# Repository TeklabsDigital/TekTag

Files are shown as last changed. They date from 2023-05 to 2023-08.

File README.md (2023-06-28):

# **TekTag Bio™ - The Open Source Biosensor**

Introducing the latest open-source project from Teklabs Digital™, a sophisticated state-of-the-art IoT biosensor for patient monitoring, telehealth, pressure are management in hospitals, cardiac monitoring, fall detection and dementia geofencing. This community project, released under an open source license, showcases our commitment to pushing the boundaries of digital design innovation.

**TekTag Bio™** is a cutting-edge biosensor for telehealth, patient monitoring, fall detection, dementia geofencing, and cardiograms. This repository houses all the necessary files and resources to understand, modify, and contribute to this innovative project.

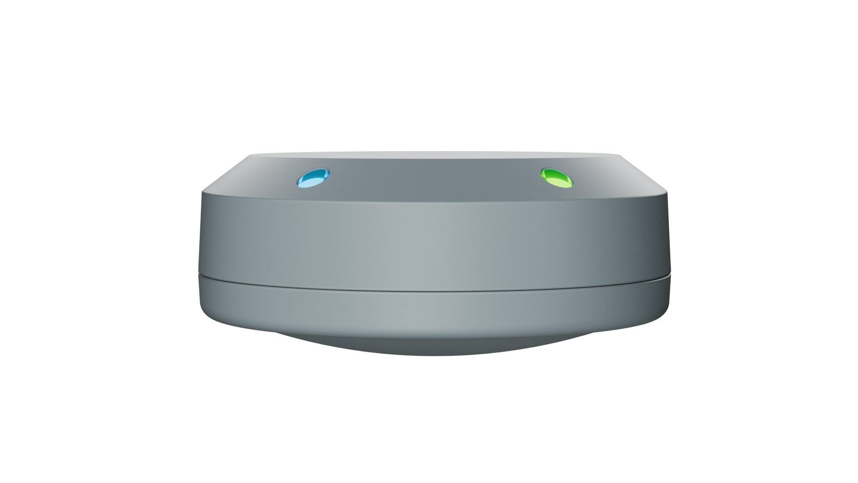
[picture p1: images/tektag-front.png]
TekTag Front


## **Table of Contents**

- [Features](#features)
- [Biosensor Applications](#biosensor-applications)
- [General Applications](#general-applications)
- [BLE Support and Mesh Technology](#ble-support-and-mesh-technology)
  - [Benefits of BLE Mesh Technology](#benefits-of-ble-mesh-technology)
- [Hardware/Electronics](#hardwareelectronics)
- [Repository Structure](#repository-structure)
- [Images](#images)
- [PCB Size and Assembly](#pcb-size-and-assembly)
- [Why is this project Open Source?](#why-is-this-project-open-source)
- [Supporting This Project](#supporting-this-project)
- [Licenses](#licenses)
- [Contact Us](#contact-us)

## [**Features**](#features)
- Small size - 28mm diameter (1.1 inches)
- All 3D manufacturing files included
- All PCB designs included
- All schematics included
- Audio feedback
- BLE 5.4 - Mesh Networking & All protocols supported by the STM32WB
- Compact integrated design
- Haptic feedback
- Qi charging
- STM32WB ARM MCU
- Touch pad for finger tap and gestures
- Ultra low power
- Visual feedback through two RGB LEDs

## [Biosensor Applications](#biosensor-applications)

Our biosensor provides a plethora of features designed to enhance the quality of life for individuals and improve the capabilities of healthcare providers. It includes:

- Telehealth capabilities
- Patient monitoring
- Pressure area management - bed turn and movement detection
- Cardiac monitoring via Ballistocardiology (BCG)
- Patient Fall detection
- Dementia geo-fence alerting
- Respiratory monitoring
- Sleep pattern monitoring

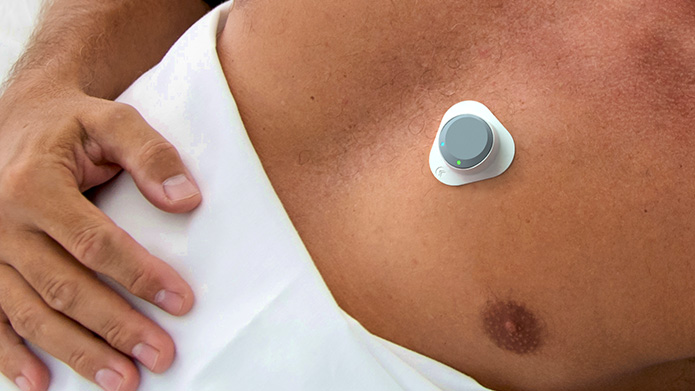
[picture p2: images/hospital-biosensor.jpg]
Hospital Biosensor


## [General Applications](#general-applications)

The small size, wireless Bluetooth, hermetically sealed enclosure, and Qi charging features of the sensor make it versatile enough to be used in a wide variety of applications, such as:

- Sports Performance Analysis
- Physical Therapy
- Elderly Care
- Virtual Reality (VR)/ Augmented Reality (AR) Systems
- Gaming
- Industrial Monitoring
- Sleep Studies
- Dance Choreography
- Wildlife Studies
- Security Systems

## [BLE Support and Mesh Technology](#ble-support-and-mesh-technology)

One of the key features of the TekTag Bio™ is its compatibility with the STM32WB ecosystem, which offers support for a variety of Bluetooth Low Energy (BLE) protocols. BLE is a power-efficient version of classic Bluetooth and is designed for short-range communication between devices. 

A particularly exciting protocol within this ecosystem is BLE Mesh technology. BLE Mesh allows for many-to-many communication, creating a network of interconnected devices that can communicate with each other. This is an essential feature when deploying large numbers of TekTag Bio™ devices in a hospital setting.

### [Benefits of BLE Mesh Technology](#benefits-of-ble-mesh-technology)

There are several key benefits of using BLE Mesh technology in a TekTag Bio™ deployment:

1. **Scalability**: BLE Mesh networks can theoretically support up to 32,767 devices, making them highly scalable. This is ideal for large-scale deployments in hospitals, where you might need to monitor many patients simultaneously.
2. **Reliability**: In a mesh network, data can take multiple paths to reach its destination, which increases the network's overall reliability. If one device fails or is disconnected, the network can automatically reconfigure itself to ensure data still reaches its destination.
3. **Range**: While individual BLE devices have a limited range, a mesh network can extend that range significantly. Each device in the network can act as a relay, passing messages from one device to another. This allows data to travel large distances across the network, making it possible to cover an entire hospital.
4. **Power Efficiency**: Despite their capabilities, BLE Mesh networks are highly power efficient. This is crucial for TekTag Bio™ devices, which need to operate for extended periods without recharging.

## [Hardware/Electronics](#hardwareelectronics)

Our biosensor utilizes a range of high-performance components to achieve its functionality:

- **STM32WB55VG:** This is a BLE 5.3 dual-core, multi-protocol 2.4 GHz radio and ultra-low-power MCU system on chip. Supporting mesh networking, the STM32WB is the brain of our sensor and responsible for signal processing and wireless communication.

- **MLPF-WB55-01E3:** This is an integrated filter module for STM32WB55, by ST. It increases board space through reduced PCB component count.

- **BQ51052BYFP:** This is a high-efficiency, Qi-compliant wireless power receiver. It enables our sensor to be charged wirelessly.

- **TLV75533PDRV:** This is a low-dropout (LDO) regulator with high power-supply rejection ratio (PSRR). It helps to provide stable power supply for our sensor.

- **KTD2052:** This is an LED driver used for status indication in our sensor.

- **LSM6DSV16XTR:** This is a system-in-package featuring a 3D digital accelerometer and a 3D digital gyroscope. It enables our sensor to detect and log movements.

## [Repository Structure](#repository-structure)

This repository is organized into several key sections:

- **Electronics:** Schematics, PCB updates and files related to the electronic components of the TekTag Bio™ biosensor.
- **Firmware/stm32:** The initial commit of the firmware for the STM32 microcontroller used in the device.
- **Mechanical:** Files related to the mechanical aspects of the biosensor, including design and assembly instructions.

## [Images](#images)

Below are some images related to the project:

### PCB Front - 6 Layers
Having a six-layer PCB with tented vias under a BGA (Ball Grid Array) is important for our product's compact size, signal integrity, thermal management, and reliability. The extra layers allow for denser routing, reducing PCB size. Tented vias prevent solder draw into vias, preventing assembly problems under tight constraints.

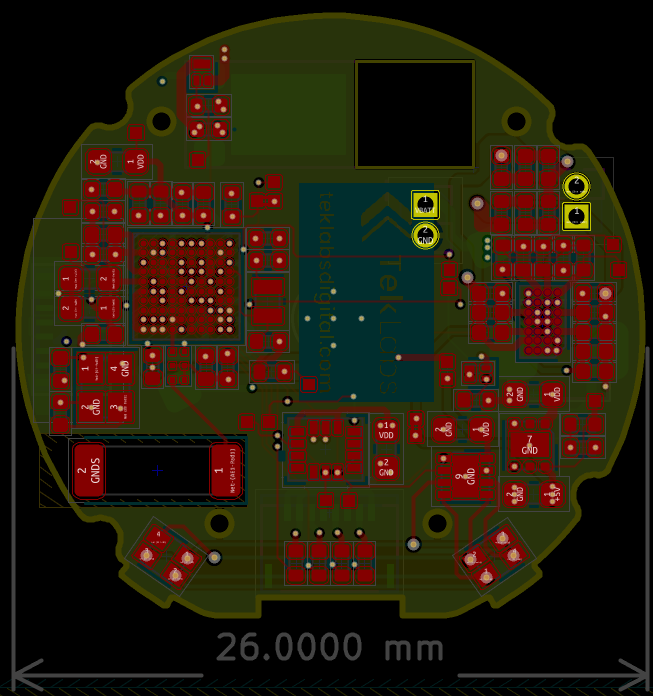
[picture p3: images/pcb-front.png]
TekTag Bio™ PCB Front


### PCB Front 3D

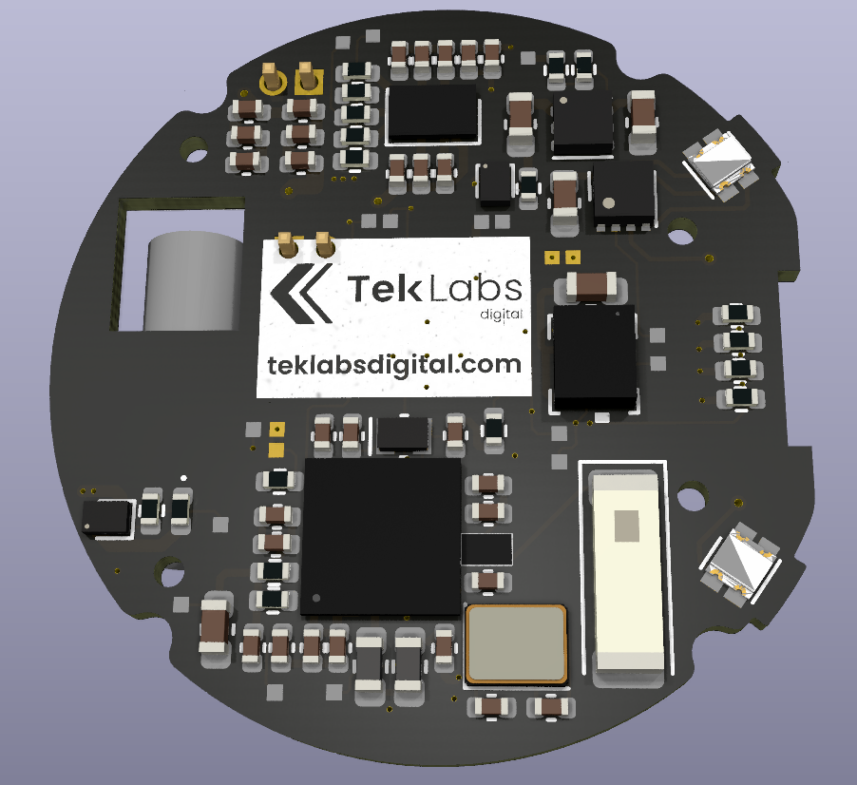
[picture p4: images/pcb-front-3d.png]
TekTag Bio™ PCB Front 3D


### PCB Back 3D

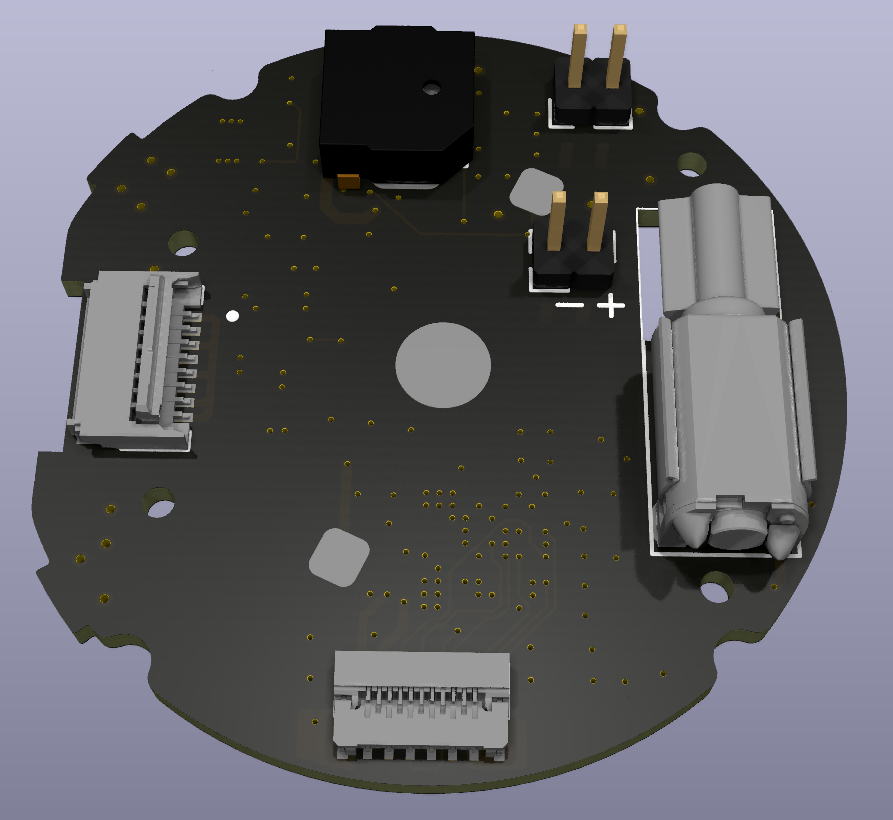
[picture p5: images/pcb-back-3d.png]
TekTag Bio™ PCB Back 3D


### TekTag Bio™ Sensor with Silicon Holder

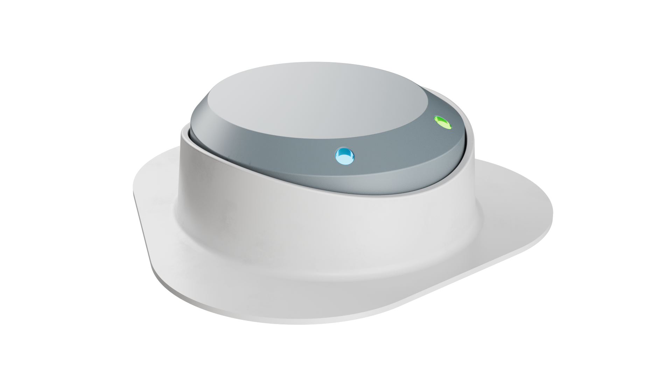
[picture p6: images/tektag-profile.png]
TekTag Bio™ Profile


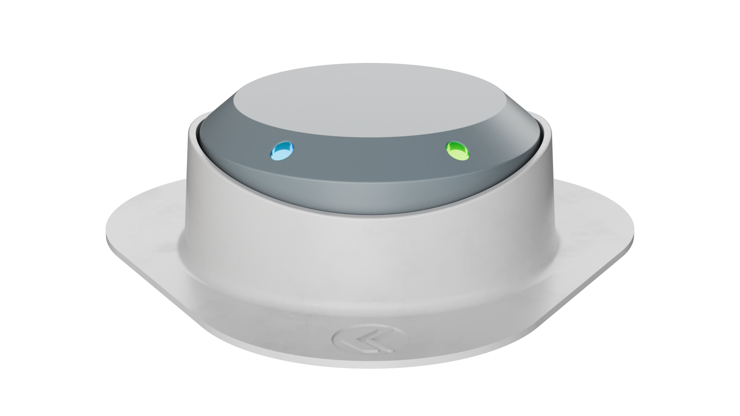
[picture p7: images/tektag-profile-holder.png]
TekTag Bio™ Profile Holder


### TekTag Bio™ Sensor Without Silicone Holder

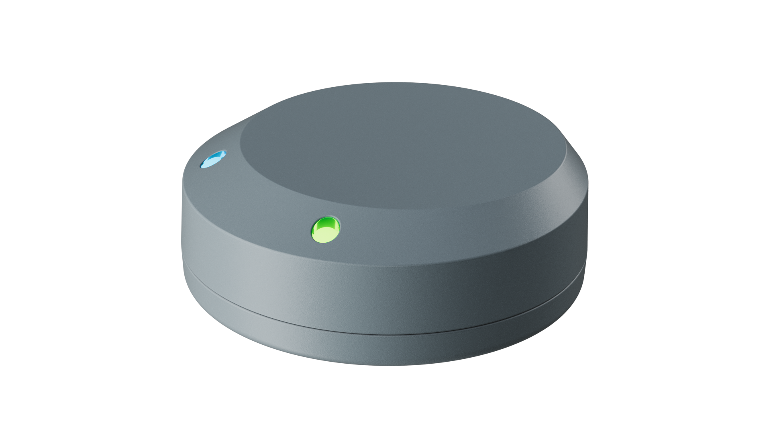
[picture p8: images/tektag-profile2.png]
TekTag Bio™ Profile 2


## [PCB Size and Assembly](#pcb-size-and-assembly)

The TekTag Bio™ is designed with a compact and highly-integrated PCB (Printed Circuit Board). Given its small size, specialized tools and expertise are required for the assembly process. This could pose a challenge for individual builders, especially those without access to such resources.

Understanding this, if there is enough interest from the community, we are prepared to step in and help. We plan to manufacture and assemble the boards for everyone at minimal cost. This not only ensures the quality and consistency of the boards but also makes the TekTag Bio™ more accessible to everyone interested in using or contributing to it.

## [Why is this project Open Source?](#why-is-this-project-open-source)

TekTag Bio™ is a project rooted in the belief that quality healthcare should be accessible to everyone, regardless of where they are in the world. By open sourcing this project, we are aiming to democratize access to technology that has the potential to significantly improve patient outcomes, particularly in developing countries where resources may be limited. 

There are several reasons why we believe an open source approach is best for this project:

1. **Community Collaboration**: Open source projects foster a unique sense of collaboration and community. People from all around the world can contribute to the project, each bringing their unique perspectives and skills to the table. This diversity can drive innovation and improve the product in ways that wouldn't be possible in a closed source project.

2. **Accelerated Development**: With more eyes on the project, issues can be identified and resolved more quickly. This can speed up the development process and result in a better final product.

3. **Transparency**: Open source projects are transparent. Anyone can look at the code and understand exactly how the product works. This transparency can build trust and make it easier for people to adopt the technology.

4. **Accessibility**: Perhaps the most important reason is that open source projects are accessible to everyone. Anyone, anywhere, can use and modify the product for their own needs. This is particularly important for healthcare technology, which has the potential to save lives and improve quality of life for millions of people.

5. **Non-profit Motivation**: As a non-profit initiative, our primary goal is to support health outcomes worldwide. Our focus is on creating a product that can have a real impact on the world, not on generating profit.

6. **Education**: Open sourcing this project also provides a valuable learning resource for students and professionals interested in biosensor technology. They can learn from and build upon the work that's already been done, accelerating their own learning and development.

By open sourcing TekTag Bio™, we hope to create a product that's not only effective, but also widely accessible and continually improving. This is our contribution to supporting healthcare in both developing countries and in first world hospitals where critical care is needed. We invite you to join us in this endeavor, whether it's by using TekTag Bio™, contributing to its development, or simply learning from the project.

## [Supporting This Project](#supporting-this-project)

TekTag Bio™ is a community-driven project, and we welcome contributions from everyone, regardless of their background or experience level. There are several ways you can support this project:

1. **Contributing Code**: If you have experience in UX/UI for the web application, Node.js for backend development, Express.js for the frontend, or STM32WB firmware engineering, your skills are particularly valuable. You can contribute directly to the codebase, helping us improve and expand the functionality of TekTag Bio™.

2. **Testing and Reporting Issues**: Even if you're not a developer, you can still contribute by testing the TekTag Bio™ and reporting any issues or bugs you find. This helps us ensure that the TekTag Bio™ is as reliable and effective as possible.

3. **Spreading the Word**: Help us grow the TekTag Bio™ community by sharing the project with others. The more people who know about TekTag Bio™, the more we can achieve.

4. **Donations**: As a not-for-profit project, we rely on donations to fund our work. If you're able to, consider making a donation to support the development of TekTag Bio™.

5. **Partnerships**: We are open to partnerships with organizations that align with our mission of improving healthcare outcomes worldwide. If you represent such an organization, please get in touch.

## [Licenses](#licenses)
Project source code, hardware designs and 3d enclosure designs are open source and licensed under the terms of the attached license, with attribution to TekLabs Digital Pty Ltd, Australia

## [Contact Us](#contact-us)
If you're interested in contributing to the TekTag Bio™ project, please contact us through our website at [https://teklabsdigital.com/contact/](https://teklabsdigital.com/contact/). We look forward to working with you to make TekTag Bio™ the best it can be!

Remember, every contribution, no matter how small, helps us move closer to our goal of improving healthcare outcomes around the world. Thank you for your support!

About TekLabs Digital Pty Ltd, Australia - Creating exceptional IoT products and advanced technologies to improve our quality of life 🌟IoT product research, innovation and design✨Let's get started!
web www.teklabsdigital.com
linkedin https://www.linkedin.com/in/trevorattemadigital/
Contact us about your design today.

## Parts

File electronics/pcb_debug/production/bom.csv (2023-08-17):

Designator | Footprint | Quantity | Value | LCSC Part #
J1 | Molex 5035661102 | 1 | SWD Trace
J2 | PinHeader_2x10_P1.27mm_Vertical | 1 | SWD Trace J Trace
J3 | PinHeader_2x05_P1.27mm_Vertical | 1 | SWD Debug
J4 | PinHeader_1x01_P2.54mm_Vertical | 1 | 5V
J5 | PinHeader_1x01_P2.54mm_Vertical | 1 | GND
JP1 | PinHeader_1x02_P2.54mm_Vertical | 1 | 5V Trace

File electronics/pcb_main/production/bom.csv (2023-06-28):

Designator | Footprint | Quantity | Value | LCSC Part #
AE1 | Johanson_2450AT43B100E | 1 | BLE Antenna
BOOT0 | MicroJump | 1 | Bridge
BT1 | CP1254 Battery | 1 | Battery_Cell
BZ1 | Transducer TE044003-4 | 1 | Buzzer
C1, C2 | 0402 | 2 | 18pF
C10, C11, C12, C13, C14, C15, C7, C8, C9 | 0402 | 9 | 100nF
C16, C17, C18 | 0402 | 3 | C1
C19, C20, C21 | 0402 | 3 | C2
C22, C27 | 0402 | 2 | 0.47uF
C23, C26 | 0402 | 2 | 22nF
C24, C25 | 0402 | 2 | 10nF
C28, C29 | 0402 | 2 | 10uF
C3, C4 | 0402 | 2 | 12pF
C30, C31, C32, C33 | 0603 | 4 | 10uF
C34 | 0402 | 1 | 1uF
C35 | 0402 | 1 | 47nF
C6 | 0603 | 1 | 4.7uF
D1 | LED_LiteOn_LTST-C19HE1WT | 1 | LEDA
D2 | LED_LiteOn_LTST-C19HE1WT | 1 | LEDB
D3 | 0402 | 1 | 1N4148
J1 | Molex 5035661102 | 1 | SWD Trace
J2 | MOLEX_5034800800 | 1 | Touch FFC
J3 | PinHeader_1x02_P1.27mm_Vertical | 1 | ExtBatt
JP1 | MicroJump-Open | 1 | 5V Trace
JP2 | MicroJump | 1 | Batt Source
L1 | 0603 | 1 | 10uH
L2 | 0603 | 1 | 10nH
L3 | PinHeader_1x02_P1.27mm_Vertical | 1 | RX Coil
M1 | SMT Motor VZ43FM1B8230001L | 1 | Motor_DC
Q1, Q2 | SOT-883 | 2 | 2N7002
R1, R12, R13, R14, R15, R2 | 0402 | 6 | 1K
R10, R11 | 0402 | 2 | 1M
R16 | 0402 | 1 | 1.5M
R3, R8 | 0402 | 2 | 47K
R4 | 0402 | 1 | 2K4
R5 | 0402 | 1 | 100K
R6 | 0402 | 1 | 820R
R7 | 0402 | 1 | 220R
R9 | 0402 | 1 | 3.3M
TH1 | 0402 | 1 | 10k???
U1 | STM32WB55VGY6TR | 1 | STM32WB55VGY6TR - Seq
U3 | MLPF-WB55-01E3 | 1 | MLPF-WB55-01E3
U4 | Texas_DSBGA-28_1.9x3.0mm_Layout4x7_P0.4mm | 1 | BQ51052BYFP
U5 | WSON-6-1EP_2x2mm_P0.65mm_EP1x1.6mm | 1 | TLV75533PDRV
U6 | DFN-8-1EP_2x2mm_P0.5mm_EP1.05x1.75mm | 1 | KTD2052
U7 | LSM6DSV16XTR | 1 | LSM6DSV16XTR
Y1 | Crystal_SMD_EuroQuartz_X22-4Pin_2.5x2.0mm | 1 | 32MHz
Y2 | Crystal_SMD_MicroCrystal_CM9V-T1A-2Pin_1.6x1.0mm | 1 | 32768kHz

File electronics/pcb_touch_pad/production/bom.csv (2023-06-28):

Designator | Footprint | Quantity | Value | LCSC Part #
J1 | FFC_12_FLEX_PCB_END | 1 | Touch FFC
T1 | TouchSlider-3_12x12mm | 1 | TouchSlider-3x3

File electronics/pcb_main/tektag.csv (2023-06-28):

Ref | Qnty | Value | Cmp name | Footprint | Description | Vendor
AE1, | 1 | BLE Antenna | Antenna_Chip | TekLabs:Johanson_2450AT43B100E | Ceramic chip antenna with pin for PCB trace
BOOT0, | 1 | Bridge | SolderJumper_2_Bridged | TekLabs:MicroJump | Solder Jumper, 2-pole, closed/bridged
BT1, | 1 | Battery_Cell | Battery_Cell | TekLabs:CP1254 Battery | Single-cell battery
BZ1, | 1 | Buzzer | Buzzer | TekLabs:Transducer TE044003-4 | Buzzer, polarized
C1, C2, | 2 | 18pF | C_Small | Capacitor_SMD:C_0402_1005Metric | Unpolarized capacitor, small symbol
C16, C17, C18, | 3 | C1 | C_Small | Capacitor_SMD:C_0402_1005Metric | Unpolarized capacitor, small symbol
C19, C20, C21, | 3 | C2 | C_Small | Capacitor_SMD:C_0402_1005Metric | Unpolarized capacitor, small symbol
C22, C27, | 2 | 0.47uF | C_Small | Capacitor_SMD:C_0402_1005Metric | Unpolarized capacitor, small symbol
C23, C26, | 2 | 22nF | C_Small | Capacitor_SMD:C_0402_1005Metric | Unpolarized capacitor, small symbol
C24, C25, | 2 | 10nF | C_Small | Capacitor_SMD:C_0402_1005Metric | Unpolarized capacitor, small symbol
C28, C29, | 2 | 10uF | C_Small | Capacitor_SMD:C_0402_1005Metric | Unpolarized capacitor, small symbol
C3, C4, | 2 | 12pF | C_Small | Capacitor_SMD:C_0402_1005Metric | Unpolarized capacitor, small symbol
C30, C31, C32, C33, | 4 | 10uF | C_Small | Capacitor_SMD:C_0603_1608Metric | Unpolarized capacitor, small symbol
C34, | 1 | 1uF | C_Small | Capacitor_SMD:C_0402_1005Metric | Unpolarized capacitor, small symbol
C35, | 1 | 47nF | C_Small | Capacitor_SMD:C_0402_1005Metric | Unpolarized capacitor, small symbol
C6, | 1 | 4.7uF | C_Polarized_Small_US | Capacitor_SMD:C_0603_1608Metric | Polarized capacitor, small US symbol
C7, C8, C9, C10, C11, C12, C13, C14, C15, | 9 | 100nF | C_Small | Capacitor_SMD:C_0402_1005Metric | Unpolarized capacitor, small symbol
D1, | 1 | LEDA | LED_RGBA | LED_SMD:LED_LiteOn_LTST-C19HE1WT | RGB LED, red/green/blue/anode
D2, | 1 | LEDB | LED_RGBA | LED_SMD:LED_LiteOn_LTST-C19HE1WT | RGB LED, red/green/blue/anode
D3, | 1 | 1N4148 | 1N4148 | Diode_SMD:D_0402_1005Metric | 100V 0.15A standard switching diode, DO-35
J1, | 1 | SWD Trace | Conn_01x11 | TekLabs:Molex 5035661102 | Generic connector, single row, 01x11, script generated (kicad-library-utils/schlib/autogen/connector/)
J2, | 1 | Touch FFC | Conn_01x08 | TekLabs:MOLEX_5034800800 | Generic connector, single row, 01x08, script generated (kicad-library-utils/schlib/autogen/connector/)
J3, | 1 | ExtBatt | Conn_01x02 | Connector_PinHeader_1.27mm:PinHeader_1x02_P1.27mm_Vertical | Generic connector, single row, 01x02, script generated (kicad-library-utils/schlib/autogen/connector/)
JP1, | 1 | 5V Trace | SolderJumper_2_Open | TekLabs:MicroJump-Open | Solder Jumper, 2-pole, open
JP2, | 1 | Batt Source | SolderJumper_2_Bridged | TekLabs:MicroJump | Solder Jumper, 2-pole, closed/bridged
L1, | 1 | 10uH | L_Small | Inductor_SMD:L_0603_1608Metric | Inductor, small symbol
L2, | 1 | 10nH | L_Small | Inductor_SMD:L_0603_1608Metric | Inductor, small symbol
L3, | 1 | RX Coil | L_Small | Connector_PinHeader_1.27mm:PinHeader_1x02_P1.27mm_Vertical | Inductor, small symbol
M1, | 1 | Motor_DC | Motor_DC | TekLabs:SMT Motor VZ43FM1B8230001L | DC Motor
Q1, Q2, | 2 | 2N7002 | 2N7002 | Package_TO_SOT_SMD:SOT-883 | 0.115A Id, 60V Vds, N-Channel MOSFET, SOT-23
R1, R2, R12, R13, R14, R15, | 6 | 1K | R_Small_US | Resistor_SMD:R_0402_1005Metric | Resistor, small US symbol
R10, R11, | 2 | 1M | R_Small | Resistor_SMD:R_0402_1005Metric | Resistor, small symbol
R16, | 1 | 1.5M | R_Small_US | Resistor_SMD:R_0402_1005Metric | Resistor, small US symbol
R3, R8, | 2 | 47K | R_Small_US | Resistor_SMD:R_0402_1005Metric | Resistor, small US symbol
R4, | 1 | 2K4 | R_Small_US | Resistor_SMD:R_0402_1005Metric | Resistor, small US symbol
R5, | 1 | 100K | R_Small_US | Resistor_SMD:R_0402_1005Metric | Resistor, small US symbol
R6, | 1 | 820R | R_Small_US | Resistor_SMD:R_0402_1005Metric | Resistor, small US symbol
R7, | 1 | 220R | R_Small_US | Resistor_SMD:R_0402_1005Metric | Resistor, small US symbol
R9, | 1 | 3.3M | R_Small_US | Resistor_SMD:R_0402_1005Metric | Resistor, small US symbol
TH1, | 1 | 10k??? | Thermistor_NTC_US | Resistor_SMD:R_0402_1005Metric | Temperature dependent resistor, negative temperature coefficient, US symbol
U1, | 1 | STM32WB55VGY6TR - Seq | STM32WB55VGY6TR - Seq | TekLabs:STM32WB55VGY6TR
U3, | 1 | MLPF-WB55-01E3 | MLPF-WB55-01E3 | TekLabs:MLPF-WB55-01E3 | 2.4 GHz Matched filter companion chip for STM32WB55Cx and STM32WB55Rx
U4, | 1 | BQ51052BYFP | BQ51052BYFP | Package_BGA:Texas_DSBGA-28_1.9x3.0mm_Layout4x7_P0.4mm | Qi v1.2, Wireless Power Receiver and Battery Charger, Vout 4.40V, DSBGA-28
U5, | 1 | TLV75533PDRV | TLV75533PDRV | Package_SON:WSON-6-1EP_2x2mm_P0.65mm_EP1x1.6mm | 500mA Low Dropout Voltage Regulator, Fixed Output 3.3V, WSON6
U6, | 1 | KTD2052 | KTD2052 | Package_DFN_QFN:DFN-8-1EP_2x2mm_P0.5mm_EP1.05x1.75mm | 12 Channel RGB LED Drivers with I2C control
U7, | 1 | LSM6DSV16XTR | LSM6DSV16XTR | TekLabs:LSM6DSV16XTR
Y1, | 1 | 32MHz | Crystal_GND24_Small | Crystal:Crystal_SMD_EuroQuartz_X22-4Pin_2.5x2.0mm | Four pin crystal, GND on pins 2 and 4, small symbol
Y2, | 1 | 32768kHz | Crystal_Small_1 | Crystal:Crystal_SMD_MicroCrystal_CM9V-T1A-2Pin_1.6x1.0mm | 32.768 kHz Â±100ppm Crystal 7pF 90 kOhms 2-SMD, No Lead

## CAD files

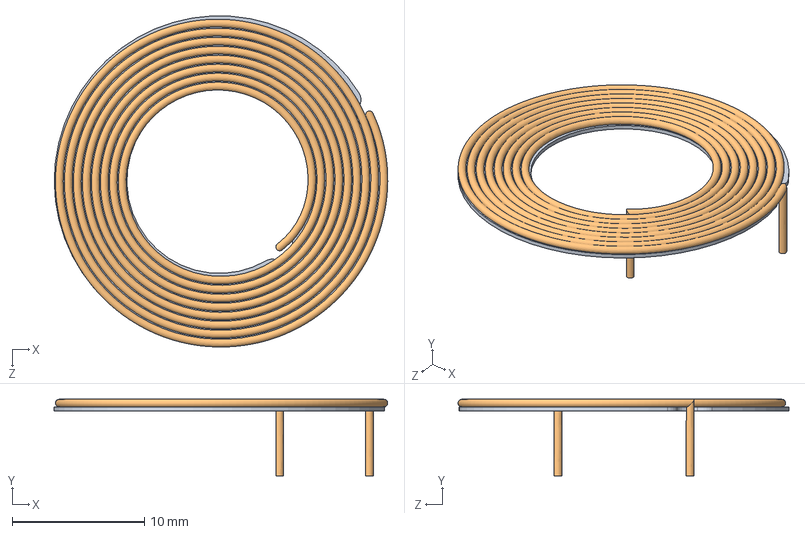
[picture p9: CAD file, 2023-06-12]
mechanical/SOLIDWORKS ORIGINAL FILE/ASSEMBLY WIRELESS CHARGING.SLDASM
25.3 x 5.79 x 25.1 mm
FERRITE
WIRELESS CHARGING COIL

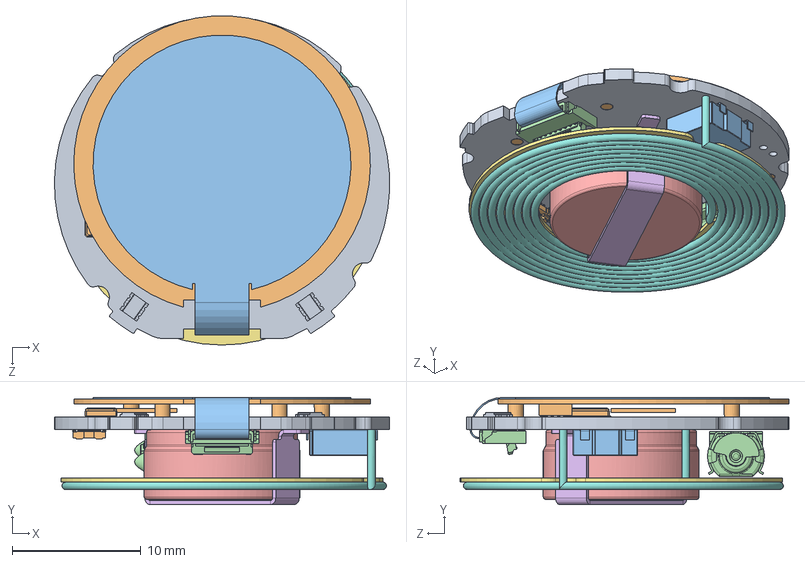
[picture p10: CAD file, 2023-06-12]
mechanical/SOLIDWORKS ORIGINAL FILE/ASSEMBLY PCB.SLDASM
26.0 x 8.30 x 25.5 mm
PCB
ELECTRONIC PART
BUZZER
VZ43FM1B8230001L
BATTERY CP1254 A3
BATTERY BRACKET
FERRITE
WIRELESS CHARGING COIL
LED LTST-C19HE1WT x 2
INNER FRAME REV
FLEXIBLE PCB
CONNECTOR

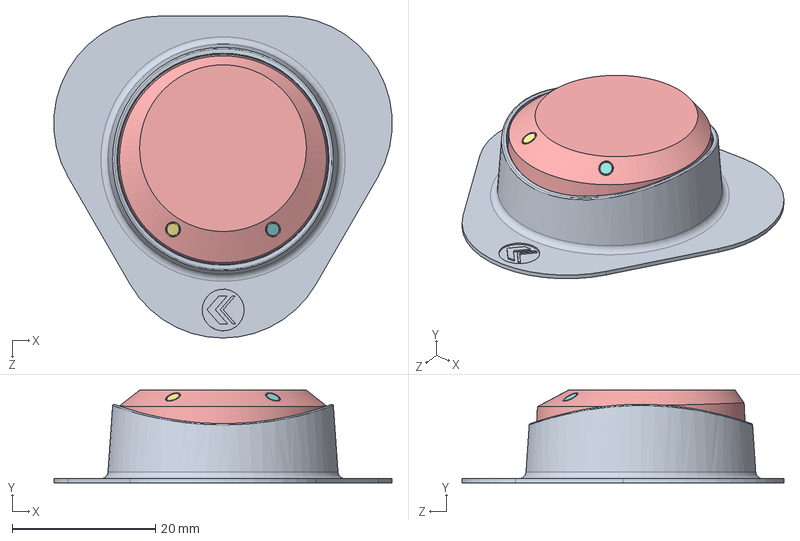
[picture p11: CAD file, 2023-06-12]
mechanical/SOLIDWORKS ORIGINAL FILE/ASSEMBLY FULL.SLDASM
47.2 x 13.0 x 45.0 mm
PCB
ELECTRONIC PART
BUZZER
VZ43FM1B8230001L
BATTERY CP1254 A3
BATTERY BRACKET
FERRITE
WIRELESS CHARGING COIL
LED LTST-C19HE1WT
INNER FRAME REV
FLEXIBLE PCB
CONNECTOR
TOP COVER
BUTTOM COVER
LED LIGHT PIPE
Mirror LED LIGHT PIPE
HOLDER

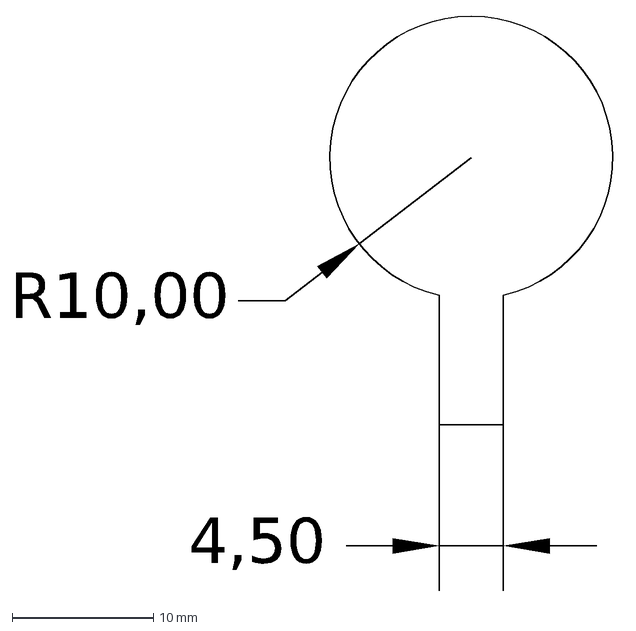
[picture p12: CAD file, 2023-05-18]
electronics/pcb_touch_pad/FLEXIBLE PCB.dxf
R10,00
4,50

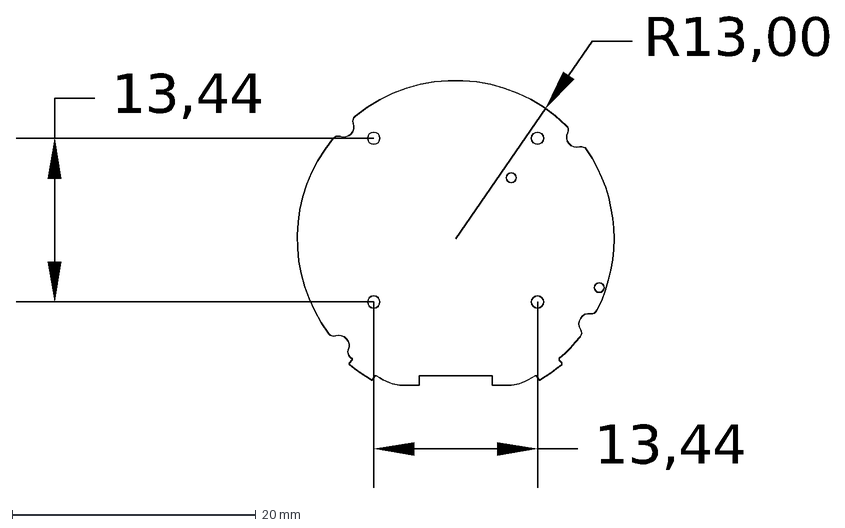
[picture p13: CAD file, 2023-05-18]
electronics/pcboutline/PCB.dxf
R13,00
13,44

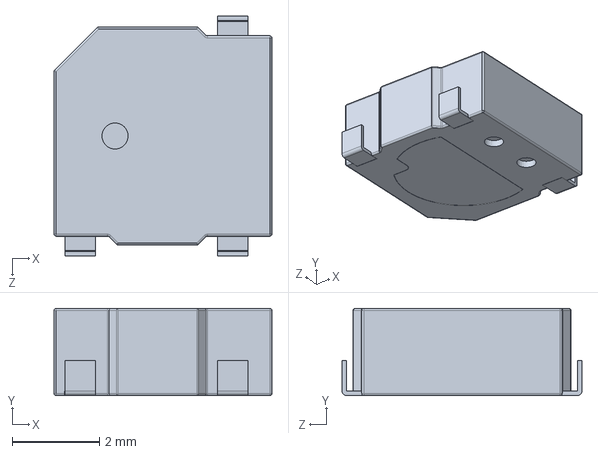
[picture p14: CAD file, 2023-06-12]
mechanical/SOLIDWORKS ORIGINAL FILE/BUZZER V1.SLDPRT
5.00 x 2.00 x 5.50 mm

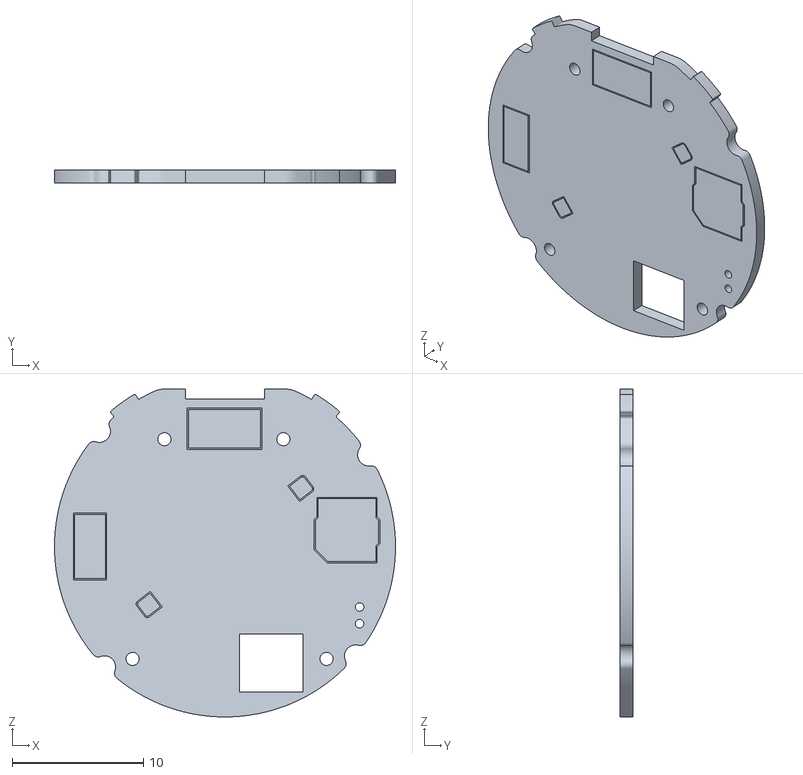
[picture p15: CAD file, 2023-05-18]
mechanical/STL FILE/PCB.STL
26.0 x 1.00 x 25.0

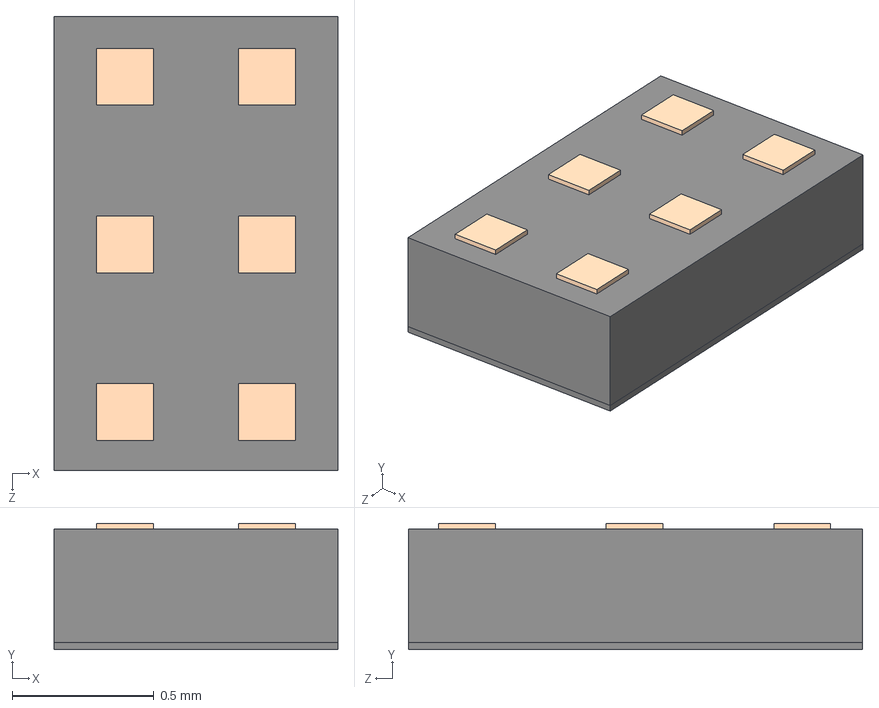
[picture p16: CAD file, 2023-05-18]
electronics/pcb_main/3dfiles/MLPF-WB55-01E3.stp
1.00 x 0.445 x 1.60 mm

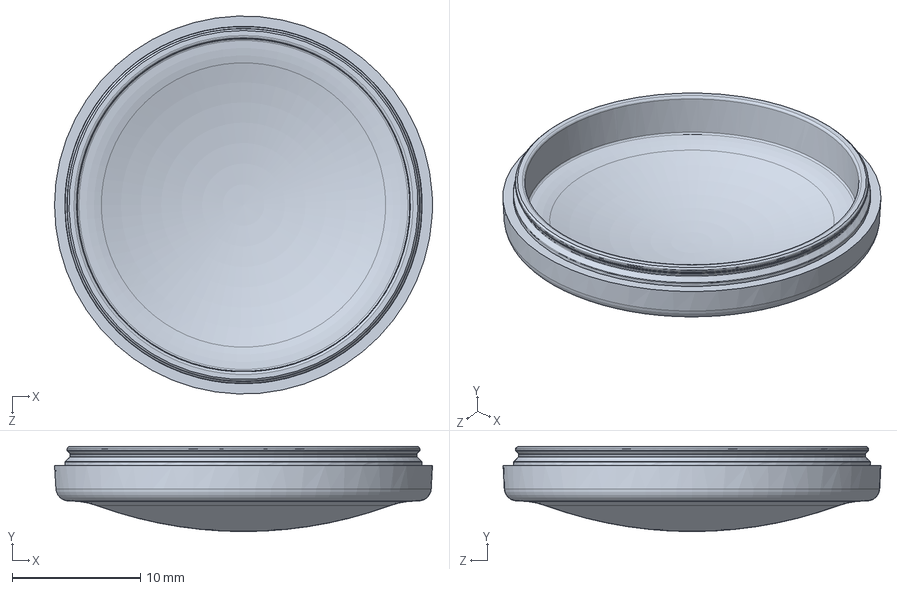
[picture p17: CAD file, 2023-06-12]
mechanical/SOLIDWORKS ORIGINAL FILE/BUTTOM COVER.SLDPRT
29.4 x 6.63 x 29.4 mm

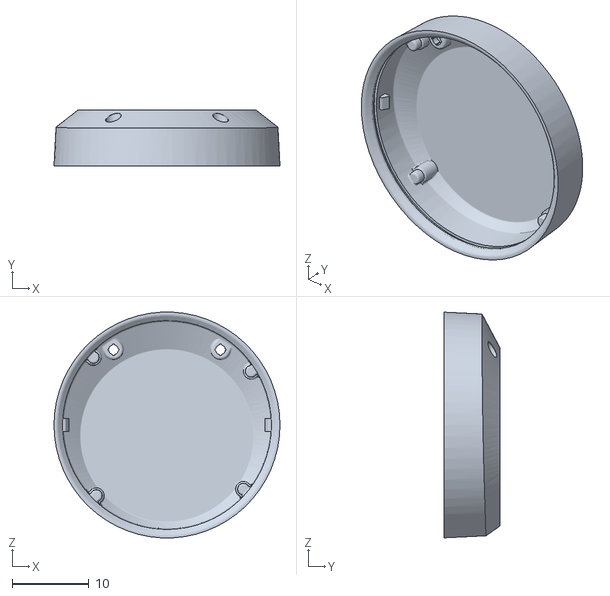
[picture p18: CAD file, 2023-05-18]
mechanical/STL FILE/TOP COVER.STL
29.4 x 7.24 x 29.4

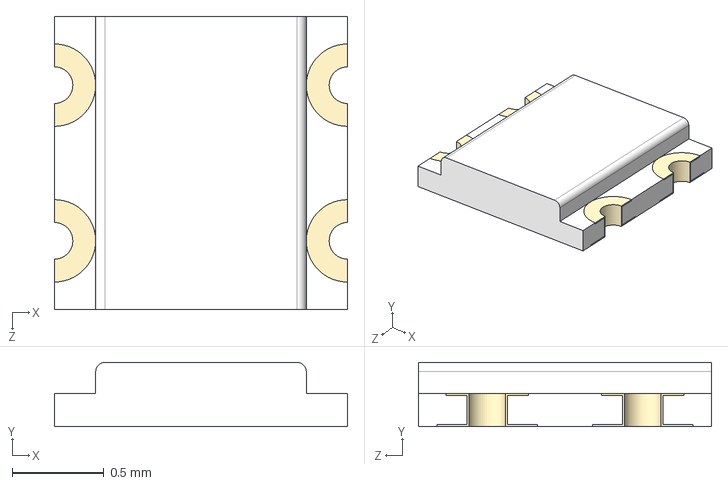
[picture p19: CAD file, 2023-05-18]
electronics/pcb_main/3dfiles/LTST-C19HE1WT.step
1.60 x 0.35 x 1.60 mm

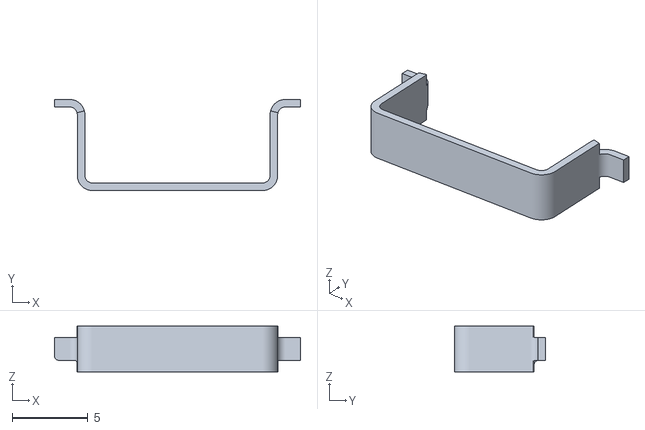
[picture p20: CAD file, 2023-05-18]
mechanical/STL FILE/BATTERY BRACKET.STL
16.2 x 6.00 x 3.00

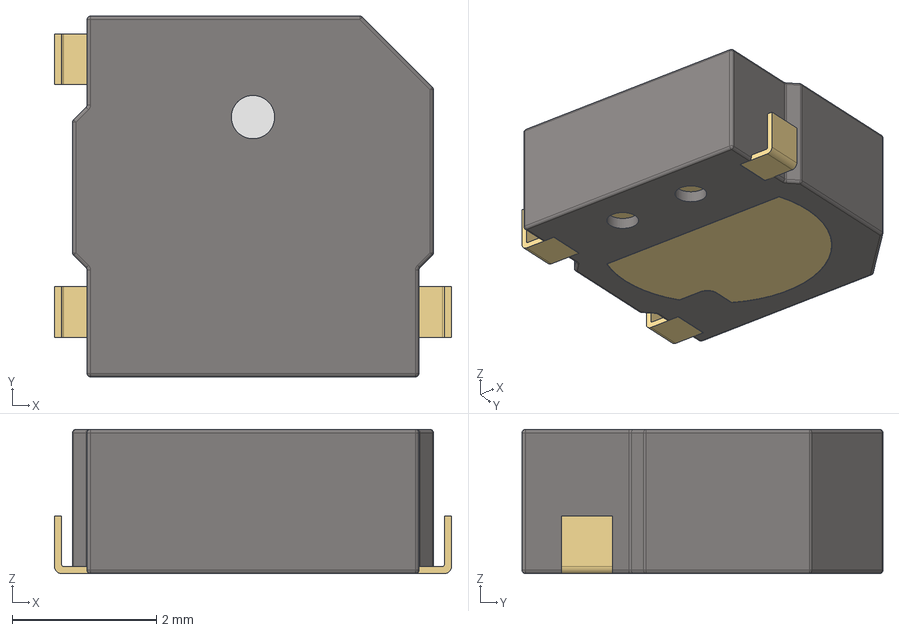
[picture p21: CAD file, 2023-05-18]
electronics/pcb_main/3dfiles/SMT-0540-T-7-R--3DModel-STEP-1.STEP
5.50 x 5.00 x 2.00 mm

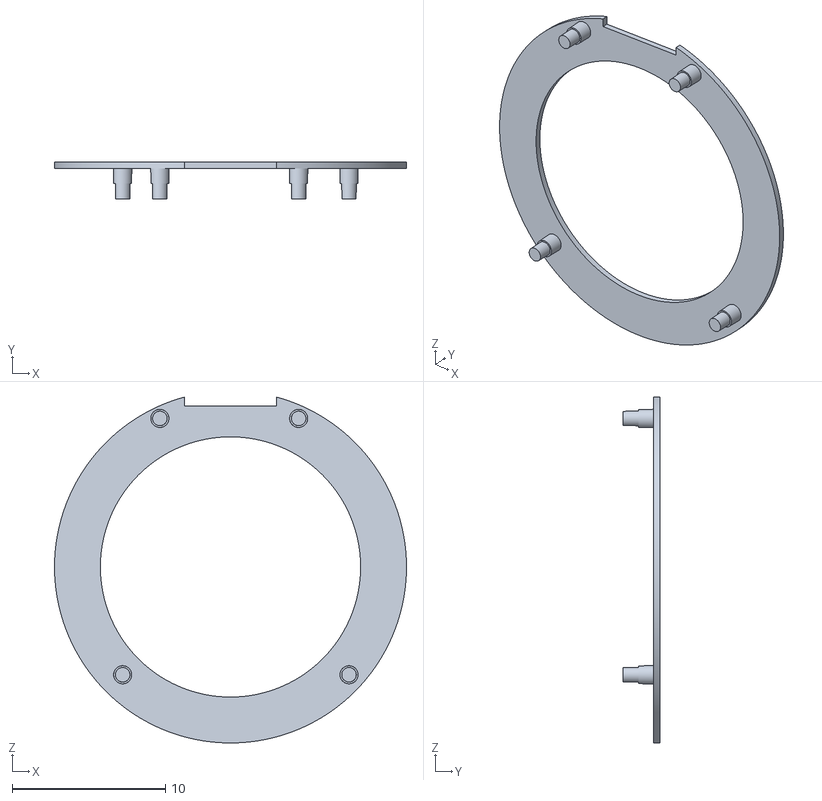
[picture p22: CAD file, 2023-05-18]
mechanical/STL FILE/INNER FRAME REV.STL
23.0 x 2.40 x 22.6

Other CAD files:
mechanical/SOLIDWORKS ORIGINAL FILE/BUZZER.SLDPRT
mechanical/SOLIDWORKS ORIGINAL FILE/LED LIGHT PIPE.SLDPRT
mechanical/STL FILE/FLEXIBLE PCB.STL
mechanical/SOLIDWORKS ORIGINAL FILE/CONNECTOR.SLDPRT
electronics/pcb_main/3dfiles/5034800800.step
electronics/pcb_main/3dfiles/5035481220.step
electronics/pcb_main/3dfiles/503566-1102.stp
electronics/pcb_main/3dfiles/BQ51052BYFPT.STEP
electronics/pcb_main/3dfiles/DFN_NP3-T1GE4_VIS.step
electronics/pcb_main/3dfiles/LGA14L_LSM6_STM.step
electronics/pcb_main/3dfiles/UFBGA129_STM32WB55VGQ6_STM.step
mechanical/DWG/FLEXIBLE PCB.DWG
mechanical/DWG/PCB.DWG
mechanical/SOLIDWORKS ORIGINAL FILE/3D/ASSEMBLY FULL.SLDASM
mechanical/SOLIDWORKS ORIGINAL FILE/3D/ASSEMBLY PCB.SLDASM
mechanical/SOLIDWORKS ORIGINAL FILE/3D/ASSEMBLY WIRELESS CHARGING.SLDASM
mechanical/SOLIDWORKS ORIGINAL FILE/3D/BATTERY BRACKET.SLDPRT
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

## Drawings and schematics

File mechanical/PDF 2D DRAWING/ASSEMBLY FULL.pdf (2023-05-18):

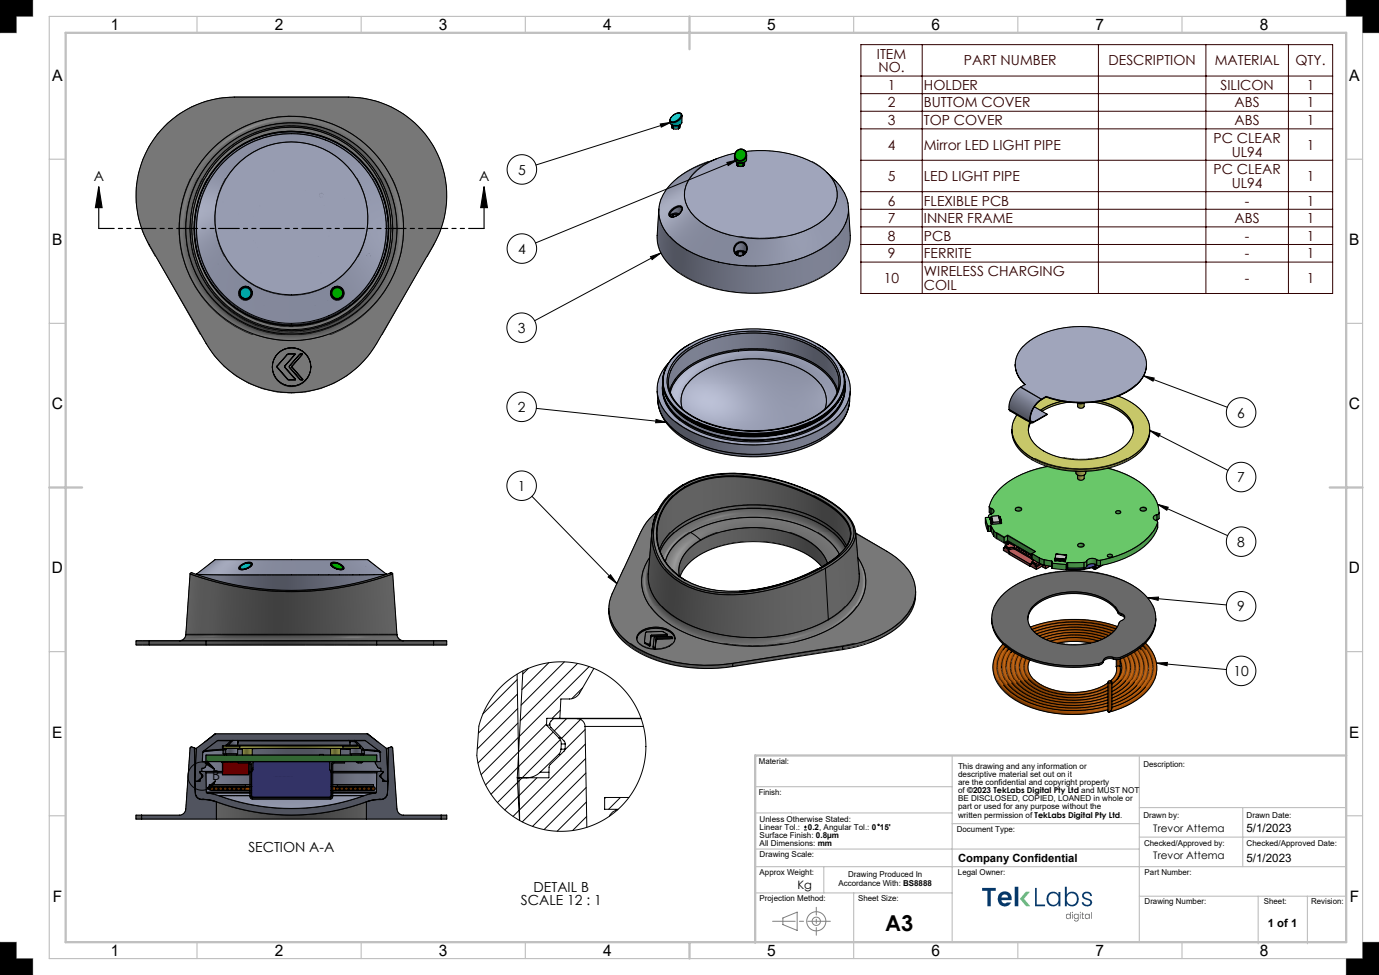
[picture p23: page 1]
SECTION A-A; DETAIL B SCALE 12 : 1; LED LIGHT PIPE; PC CLEAR; Document Type:; Drawn by: Trevor Attema

ITEM NO. | PART NUMBER | DESCRIPTION | MATERIAL | QTY.
1 | HOLDER | | SILICON | 1
2 | BUTTOM COVER | | ABS | 1
3 | TOP COVER | | ABS | 1
4 | Mirror LED LIGHT PIPE | | PC CLEAR UL94 | 1

6 | FLEXIBLE PCB | - | 1
7 | INNER FRAME | ABS | 1
8 | PCB | - | 1
9 | FERRITE | - | 1
10 | WIRELESS CHARGING COIL | - | 1

This drawing and any information or
descriptive material set out on it
are the confidential and copyright property
of ©2023 TekLabs Digital Pty Ltd and MUST NOT
BE DISCLOSED, COPIED, LOANED in whole or
part or used for any purpose without the
written permission of TekLabs Digital Pty Ltd.

Drawn Date: Unless Otherwise Stated:
Linear Tol.: 0.2, Angular Tol.: 0 15'
Surface Finish: 0.8µm
All Dimensions: mm

Checked/Approved by: Trevor Attema | Checked/Approved Date: 5/1/2023

Drawing Scale: | Company Confidential
Approx Weight: Kg | Drawing Produced In Accordance With: BS8888 | Legal Owner: | Part Number:
Projection Method: | | Sheet Size: A3

Drawing Number: | Sheet: 1 of 1 | Revision:

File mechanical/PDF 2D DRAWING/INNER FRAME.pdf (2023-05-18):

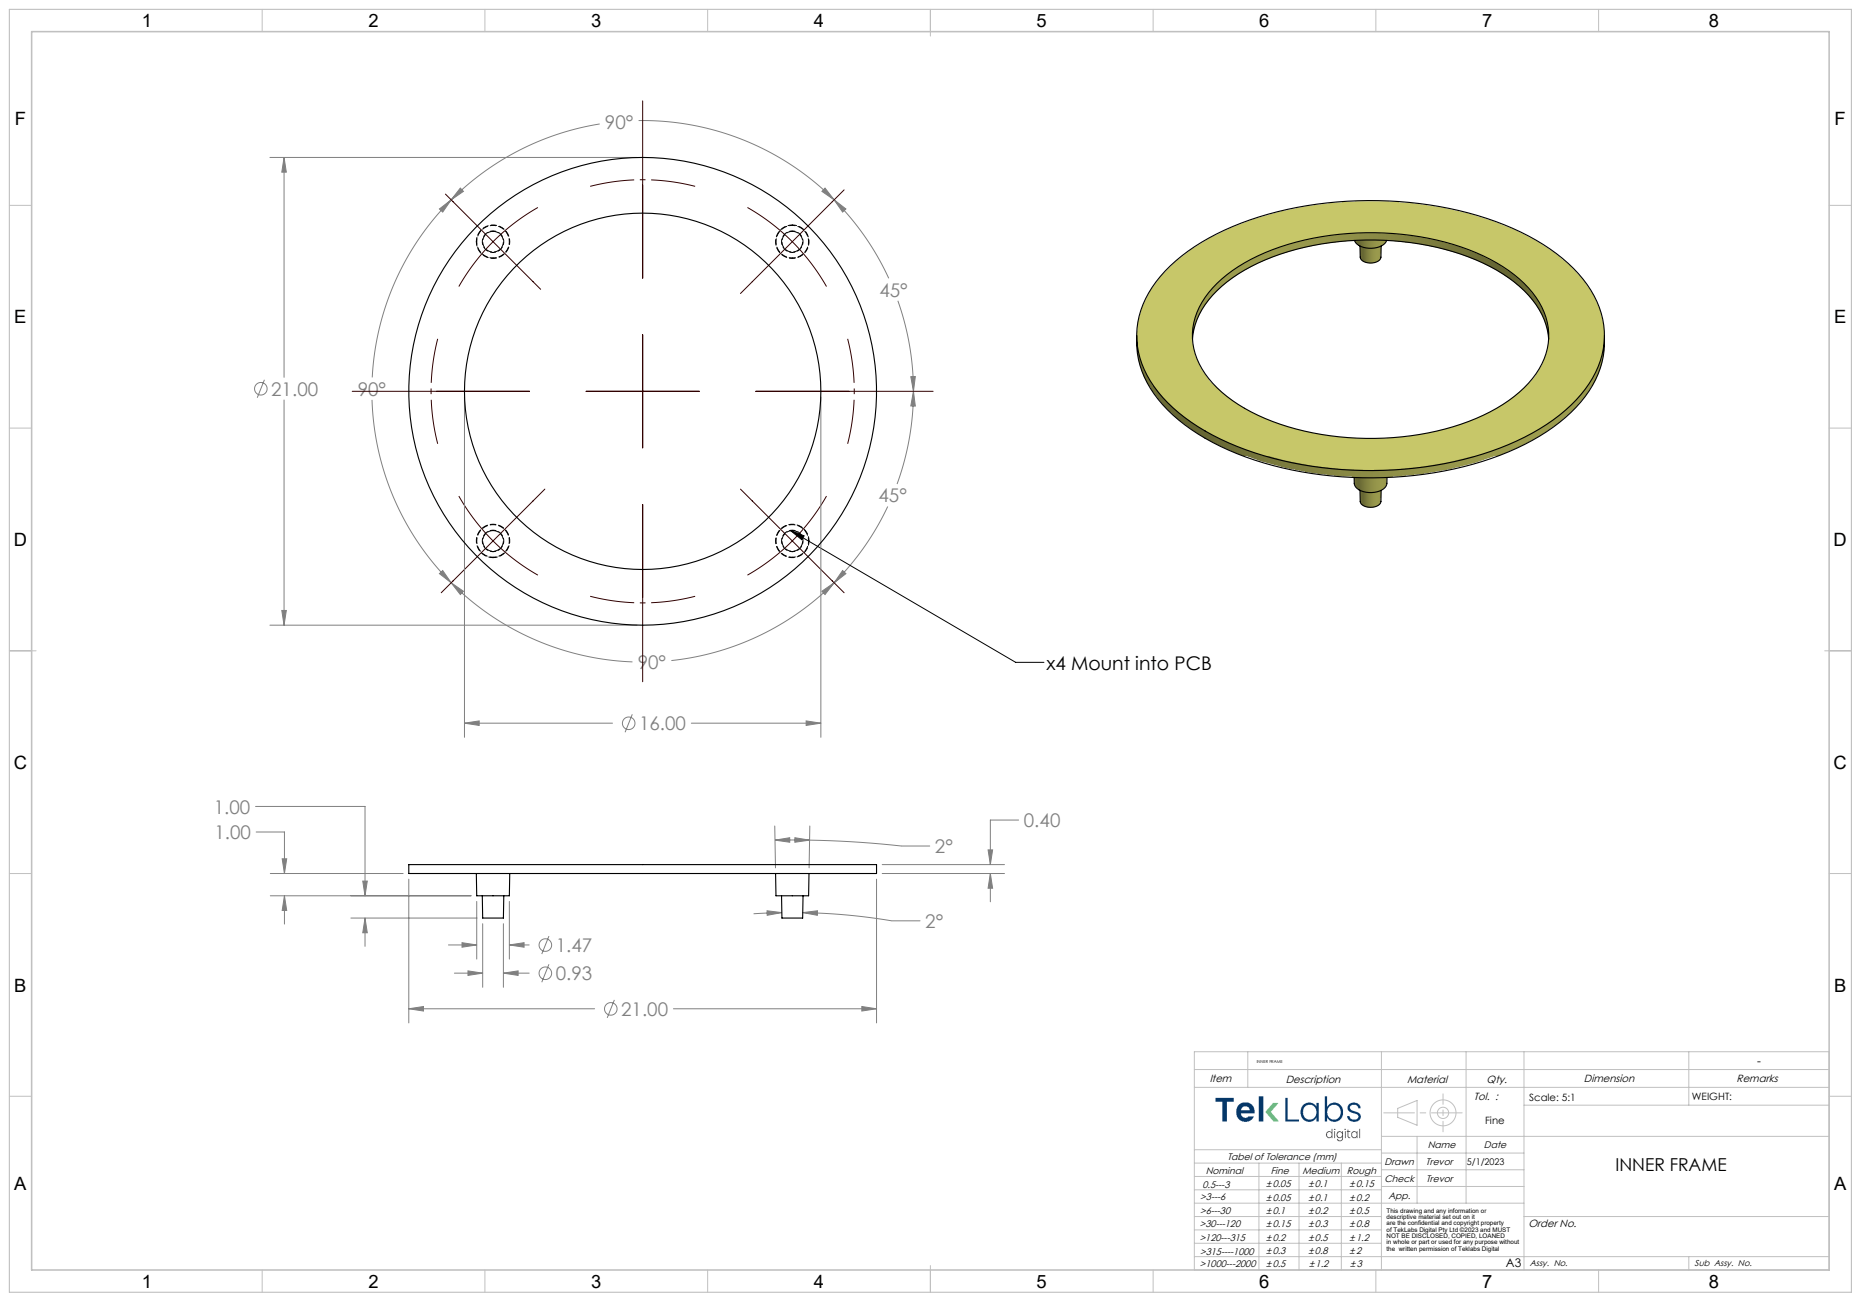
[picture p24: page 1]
Tol. :; Order No.; Nominal; Fine Medium Rough; Tabel of Tolerance (mm); Scale: 5:1; WEIGHT:; Assy. No.; INNER FRAME 5/1/2023; INNER FRAME

x4 Mount into PCB

This drawing and any information or
descriptive material set out on it
are the confidential and copyright property
of TekLabs Digital Pty Ltd ©2023 and MUST
NOT BE DISCLOSED, COPIED, LOANED
in whole or part or used for any purpose without
the written permission of Teklabs Digital

Sub Assy. No.

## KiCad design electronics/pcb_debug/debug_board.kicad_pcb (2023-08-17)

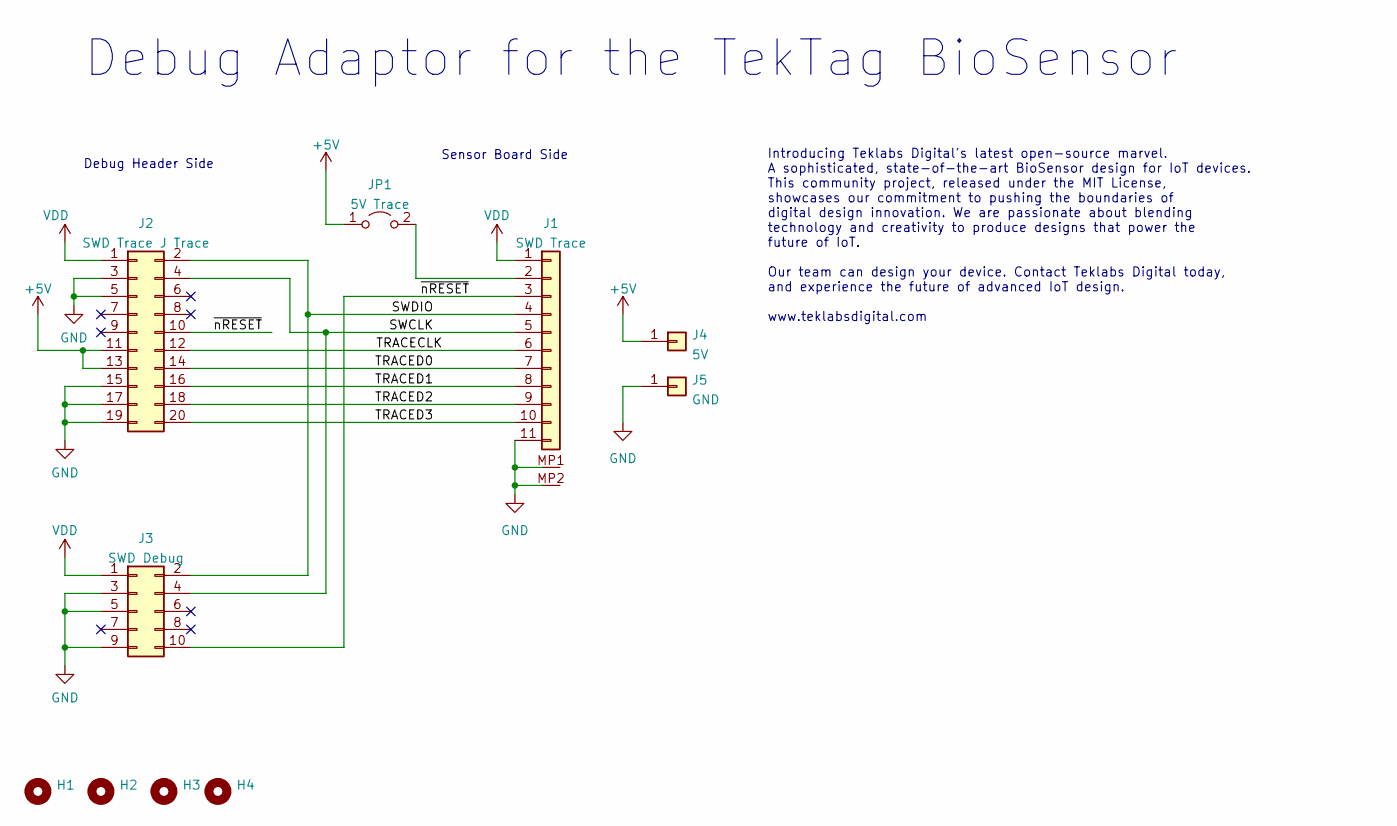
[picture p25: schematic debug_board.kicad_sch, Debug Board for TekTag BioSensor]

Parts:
H1, H2, H3, H4: MountingHole; MountingHole_3.7mm_Pad_TopBottom
J1: SWD Trace; Molex 5035661102; Digikey 900-5035661102CT-ND
J2: SWD Trace J Trace; PinHeader_2x10_P1.27mm_Vertical; Digikey 2057-HPH2-A-20-UA-ND
J3: SWD Debug; PinHeader_2x05_P1.27mm_Vertical
J4: 5V; PinHeader_1x01_P2.54mm_Vertical
J5: GND; PinHeader_1x01_P2.54mm_Vertical
JP1: 5V Trace; PinHeader_1x02_P2.54mm_Vertical

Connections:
+5V: J2.11, J2.13, J4.1, JP1.1 (A)
/SWCLK: J1.5, J2.4, J3.4
/SWDIO: J1.4, J2.2, J3.2
/TRACECLK: J1.6, J2.12
/TRACED0: J1.7, J2.14
/TRACED1: J1.8, J2.16
/TRACED2: J1.9, J2.18
/TRACED3: J1.10, J2.20
/~nRESET: J1.3, J2.10, J3.10
GND: J1.11, J1.MP1, J1.MP2, J2.3, J2.5, J2.15, J2.17, J2.19, J3.3, J3.5, J3.9, J5.1
unnamed: J1.2, JP1.2 (B)
VDD: J1.1, J2.1, J3.1

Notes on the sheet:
Sensor Board Side
Debug Adaptor for the TekTag BioSensor
Debug Header Side
Introducing Teklabs Digital's latest open-source marvel. A sophisticated, state-of-the-art BioSensor design for IoT devices. This community project, released under the MIT License, showcases our commitment to pushing the boundaries of digital design innovation. We are passionate about blending tech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

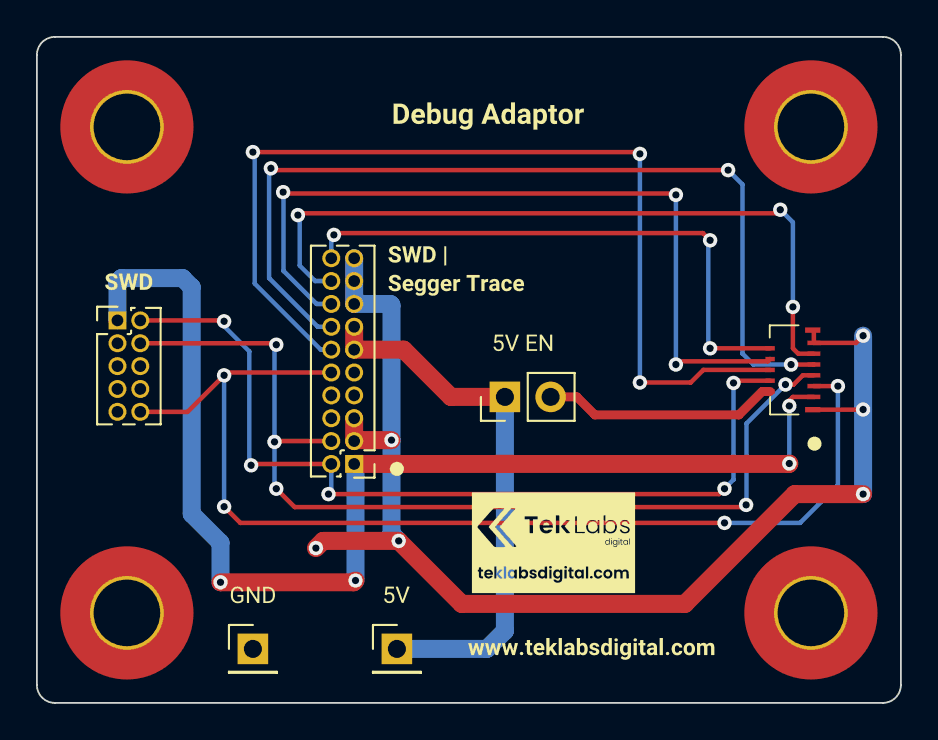
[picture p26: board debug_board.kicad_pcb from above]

Board: 2 copper layers, 48.0 x 37.0 mm, 17 parts (0 on the bottom side), 12 nets.

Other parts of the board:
kibuzzard-64C06F13: G***; kibuzzard-64C06F13
kibuzzard-64C06F53: G***; kibuzzard-64C06F53
kibuzzard-64C082C5: G***; kibuzzard-64C082C5
kibuzzard-64C0828D: G***; kibuzzard-64C0828D
kibuzzard-64C06064: G***; kibuzzard-64C06064
kibuzzard-64C08352: G***; kibuzzard-64C08352
kibuzzard-64757A2A: G***; kibuzzard-64757A2A

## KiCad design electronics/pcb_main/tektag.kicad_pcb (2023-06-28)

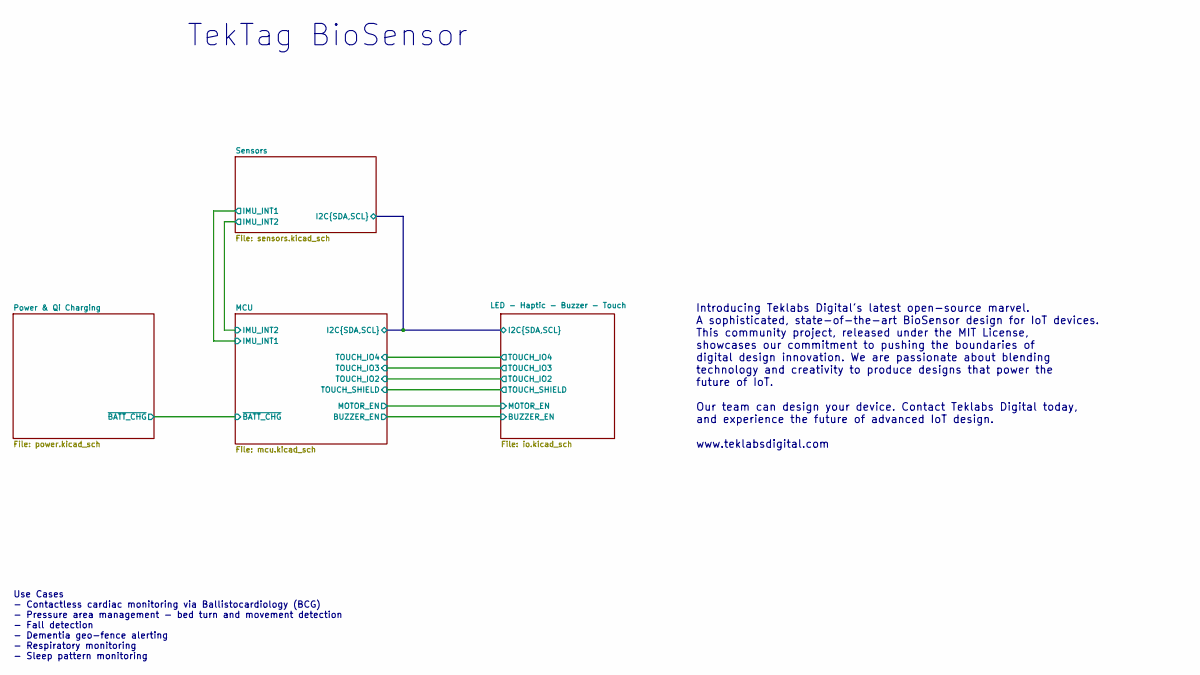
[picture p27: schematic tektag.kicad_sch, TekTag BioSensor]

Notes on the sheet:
Introducing Teklabs Digital's latest open-source marvel. A sophisticated, state-of-the-art BioSensor design for IoT devices. This community project, released under the MIT License, showcases our commitment to pushing the boundaries of digital design innovation. We are passionate about blending tech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
Use Cases - Contactless cardiac monitoring via Ballistocardiology (BCG) - Pressure area management - bed turn and movement detection - Fall detection - Dementia geo-fence alerting - Respiratory monitoring - Sleep pattern monitoring
TekTag BioSensor

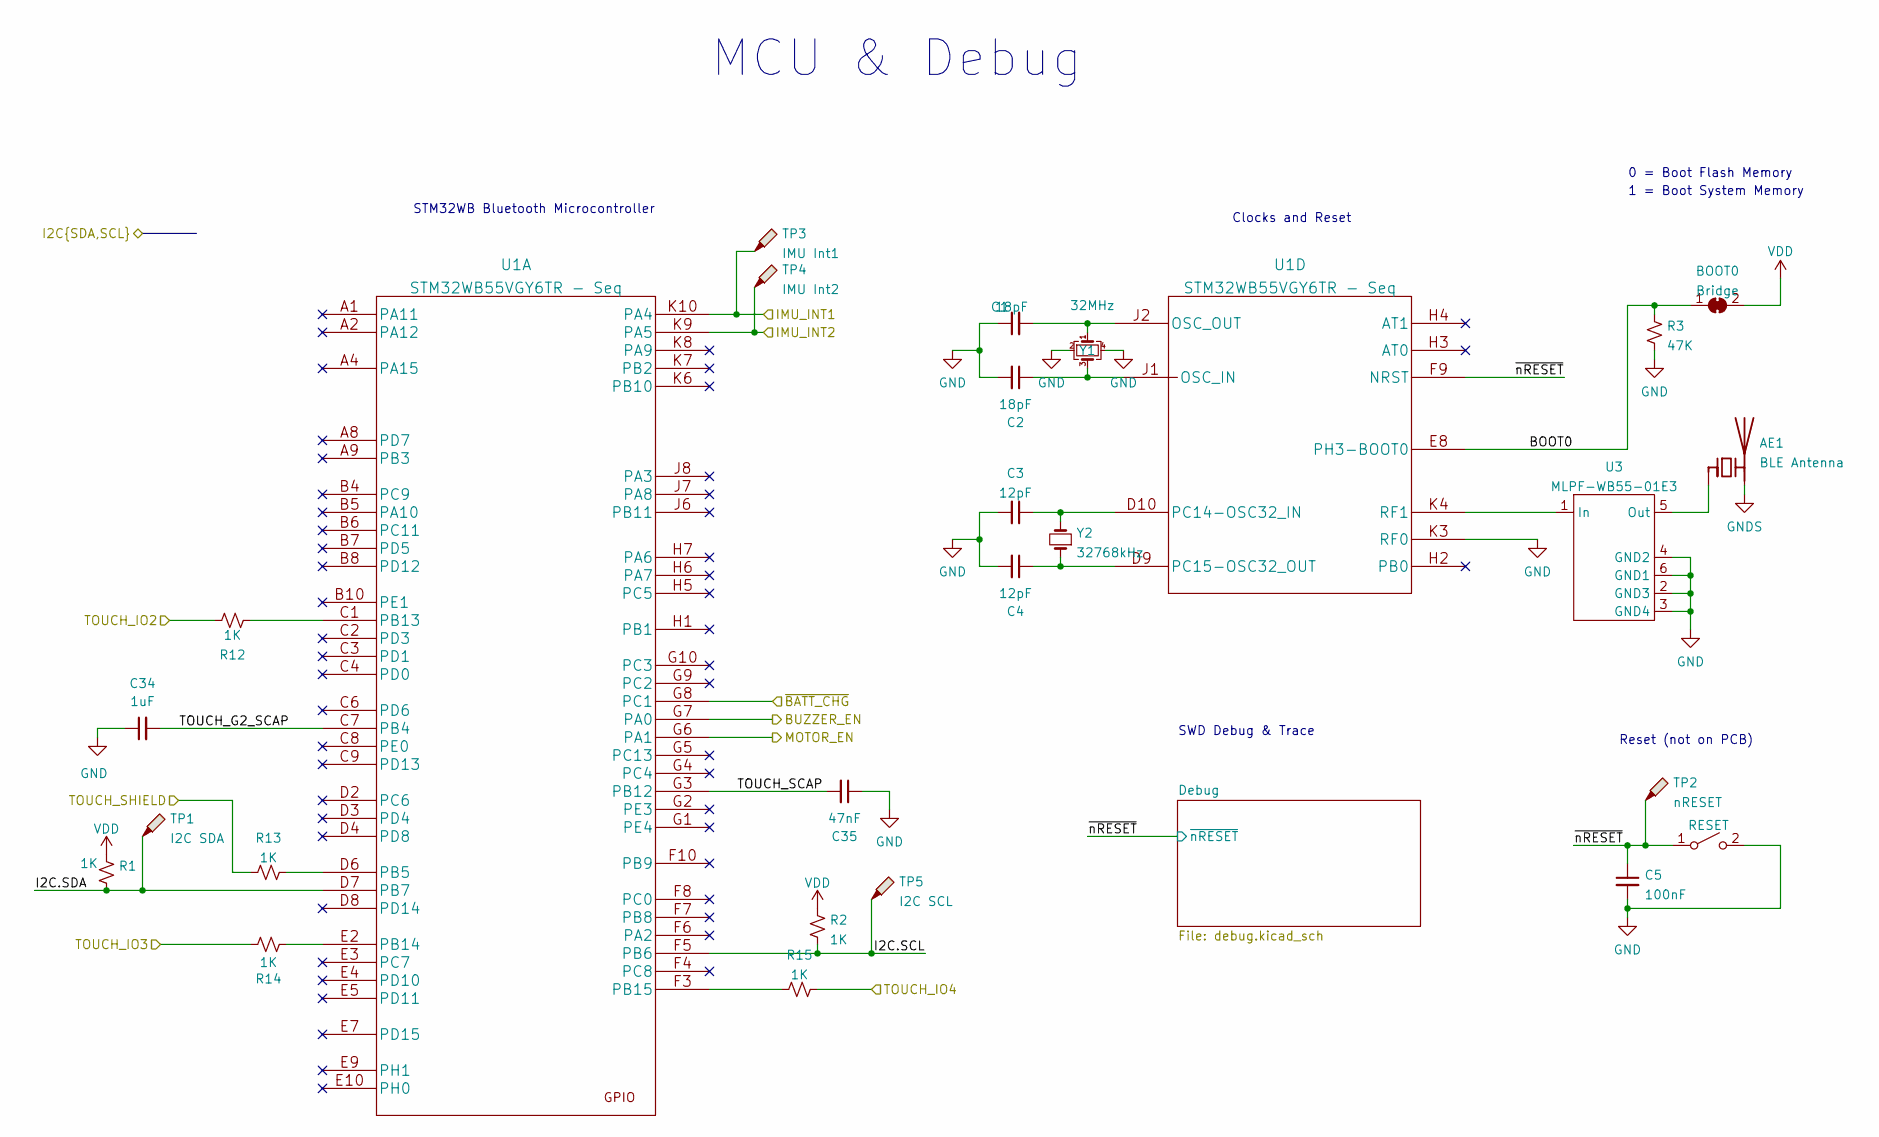
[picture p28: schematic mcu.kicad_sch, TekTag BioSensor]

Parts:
AE1: BLE Antenna
BOOT0: Bridge
C1, C2: 18pF; Digikey GCM1555C1H180JA16D
C3, C4: 12pF; Digikey GCM1555C1H120JA16J
C5: 100nF; Digikey GRT155R71H104KE01D
C34: 1uF; Digikey EMK105BJ105KV-F
C35: 47nF; Digikey GRM155R71H473ME14D
R1, R2, R12, R13, R14, R15: 1K; Digikey 1292-WR04X1001FTLCT-ND
R3: 47K; Digikey 311-47.0KLRCT-ND
SW1: RESET; Digikey B3U-1100P
TP1: I2C SDA
TP2: nRESET
TP3: IMU Int1
TP4: IMU Int2
TP5: I2C SCL
U1: STM32WB55VGY6TR - Seq
U3: MLPF-WB55-01E3; Digikey 497-19088-2-ND
Y1: 32MHz; Digikey 1923-830107820709CT-ND
Y2: 32768kHz; Digikey 2195-CM9V-T1A-32.768KHZ-7PF-100PPM-TA-Q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

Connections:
/LED - Haptic - Buzzer - Touch/BUZZER_EN: U1.G7 (PA0); also elsewhere on the board
/LED - Haptic - Buzzer - Touch/I2C.SCL: R2.2, TP5.1, U1.F5 (PB6); also elsewhere on the board
/LED - Haptic - Buzzer - Touch/I2C.SDA: R1.2, TP1.1, U1.D7 (PB7); also elsewhere on the board
/LED - Haptic - Buzzer - Touch/MOTOR_EN: U1.G6 (PA1); also elsewhere on the board
/LED - Haptic - Buzzer - Touch/TOUCH_IO2: R12.2; also elsewhere on the board
/LED - Haptic - Buzzer - Touch/TOUCH_IO3: R14.2; also elsewhere on the board
/LED - Haptic - Buzzer - Touch/TOUCH_IO4: R15.2; also elsewhere on the board
/LED - Haptic - Buzzer - Touch/TOUCH_SHIELD: R13.2; also elsewhere on the board
/MCU/BOOT0: BOOT0.1 (A), R3.1, U1.E8 (PH3-BOOT0)
/MCU/IMU_INT1: TP3.1, U1.K10 (PA4); also elsewhere on the board
/MCU/IMU_INT2: TP4.1, U1.K9 (PA5); also elsewhere on the board
/MCU/TOUCH_G2_SCAP: C34.2, U1.C7 (PB4)
/MCU/TOUCH_SCAP: C35.2, U1.G3 (PB12)
/MCU/~BATT_CHG: U1.G8 (PC1); also elsewhere on the board
/MCU/~nRESET: C5.1, SW1.1 (A), TP2.1, U1.F9 (NRST); also elsewhere on the board
GND: C1.1, C2.2, C3.2, C4.2, C5.2, C34.1, C35.1, R3.2, SW1.2 (B), U1.K3 (RF0), U3.2 (GND3), U3.3 (GND4), U3.4 (GND2), U3.6 (GND1), Y1.2, Y1.4; also elsewhere on the board
GNDS: AE1.2 (PCB_Trace)
unnamed: AE1.1 (FEED), U3.5 (Out)
unnamed: C1.2, U1.J2 (OSC_OUT), Y1.1
unnamed: C2.1, U1.J1 (OSC_IN), Y1.3
unnamed: C3.1, U1.D10 (PC14-OSC32_IN), Y2.2
unnamed: C4.1, U1.D9 (PC15-OSC32_OUT), Y2.1
unnamed: R12.1, U1.C1 (PB13)
unnamed: R13.1, U1.D6 (PB5)
unnamed: R14.1, U1.E2 (PB14)
unnamed: R15.1, U1.F3 (PB15)
unnamed: U1.K4 (RF1), U3.1 (In)
VDD: BOOT0.2 (B), R1.1, R2.1; also elsewhere on the board

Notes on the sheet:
0 = Boot Flash Memory
1 = Boot System Memory
Reset (not on PCB)
MCU & Debug
SWD Debug & Trace
Clocks and Reset
STM32WB Bluetooth Microcontroller

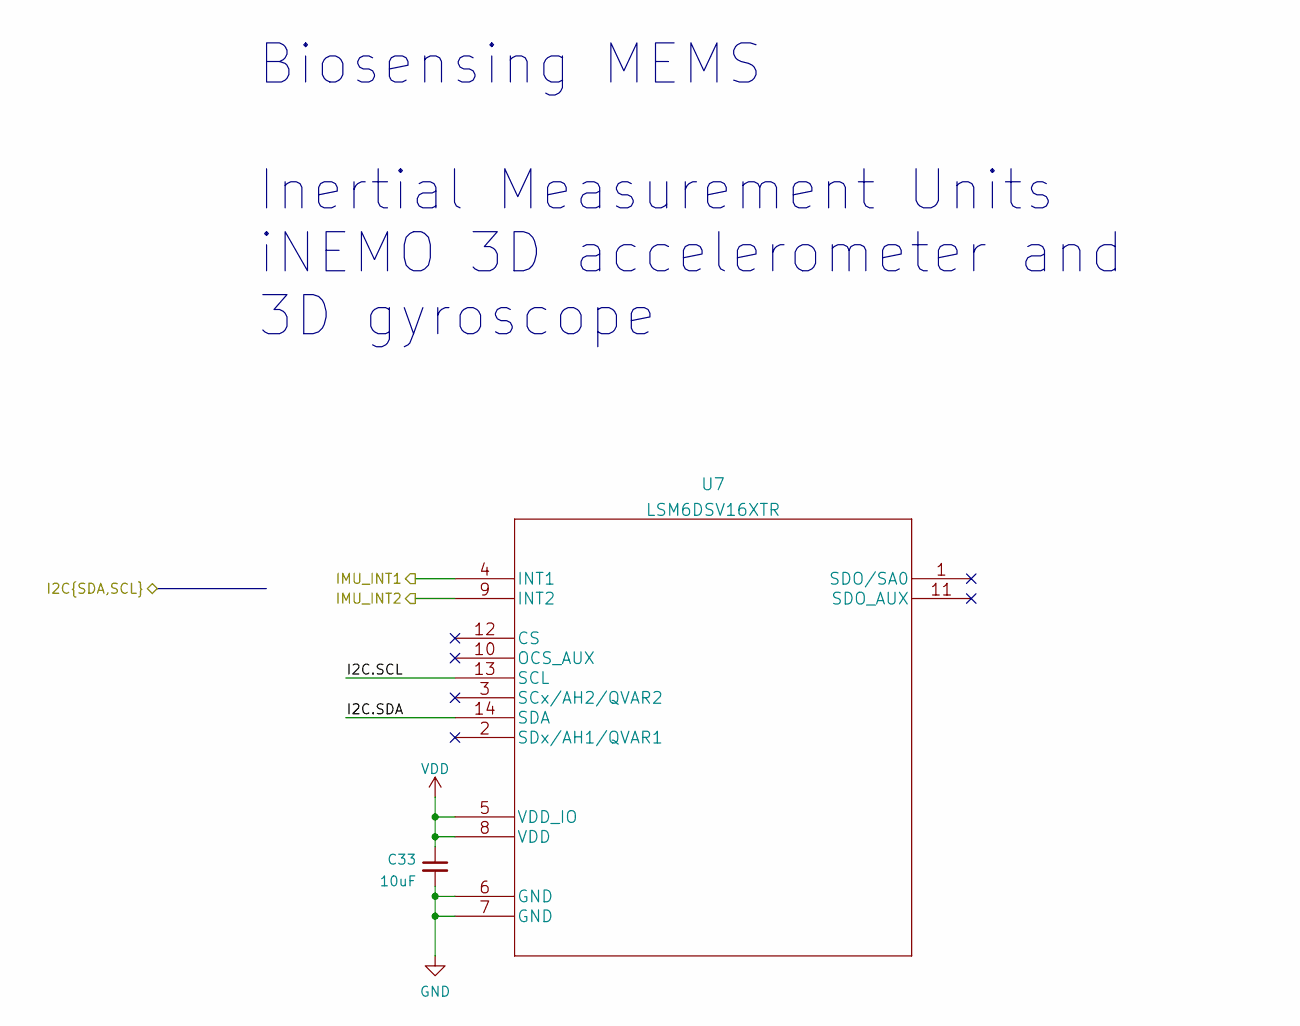
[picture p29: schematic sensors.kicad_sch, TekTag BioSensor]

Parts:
C33: 10uF; Digikey GRM188R6YA106MA73D
U7: LSM6DSV16XTR

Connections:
/LED - Haptic - Buzzer - Touch/I2C.SCL: U7.13 (SCL); also elsewhere on the board
/LED - Haptic - Buzzer - Touch/I2C.SDA: U7.14 (SDA); also elsewhere on the board
/MCU/IMU_INT1: U7.4 (INT1); also elsewhere on the board
/MCU/IMU_INT2: U7.9 (INT2); also elsewhere on the board
GND: C33.2, U7.6 (GND), U7.7 (GND); also elsewhere on the board
VDD: C33.1, U7.5 (VDD_IO), U7.8 (VDD); also elsewhere on the board

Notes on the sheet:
Biosensing MEMS Inertial Measurement Units iNEMO 3D accelerometer and 3D gyroscope

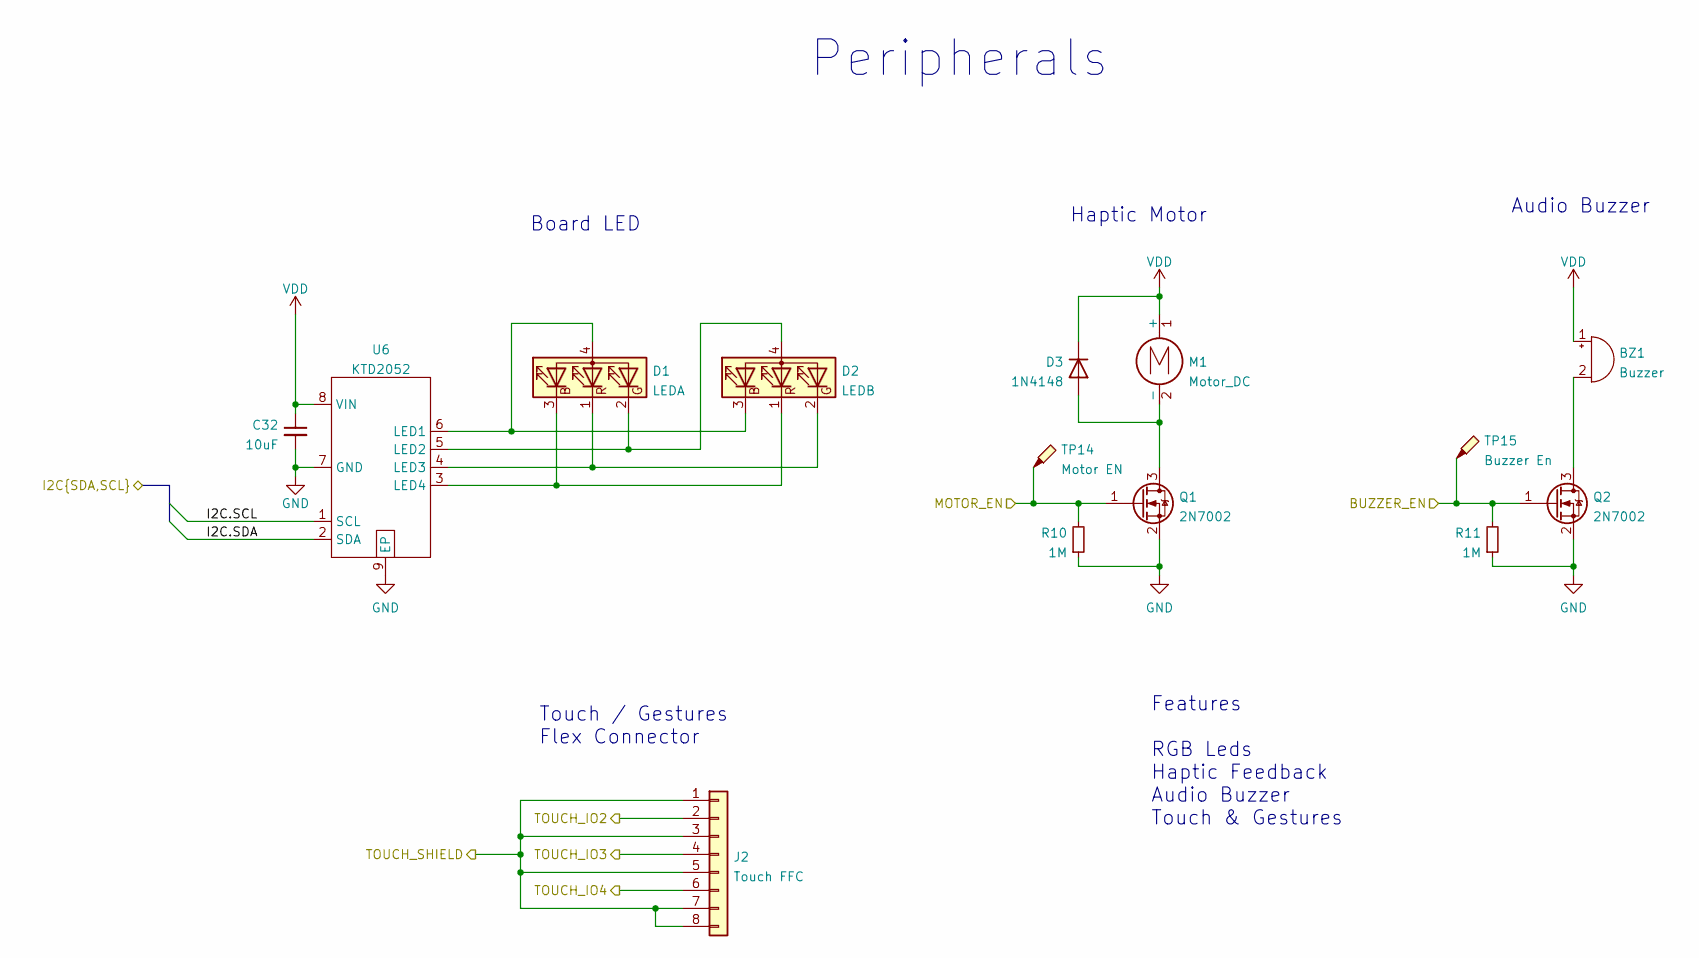
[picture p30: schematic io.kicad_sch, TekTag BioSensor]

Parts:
BZ1: Buzzer
C32: 10uF; Digikey GRM188R6YA106MA73D
D1: LEDA; Digikey LTST-C19HE1WT
D2: LEDB; Digikey LTST-C19HE1WT
D3: 1N4148; Digikey 1N4148WL2-TP
J2: Touch FFC
M1: Motor_DC; Digikey 1670-VZ43FM1B8230001LCT-ND
Q1, Q2: 2N7002; Digikey 2N7002KL3A-TP
R10, R11: 1M; Digikey 311-1.00MLRCT-ND
TP14: Motor EN
TP15: Buzzer En
U6: KTD2052

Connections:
/LED - Haptic - Buzzer - Touch/BUZZER_EN: Q2.1 (G), R11.2, TP15.1; also elsewhere on the board
/LED - Haptic - Buzzer - Touch/I2C.SCL: U6.1 (SCL); also elsewhere on the board
/LED - Haptic - Buzzer - Touch/I2C.SDA: U6.2 (SDA); also elsewhere on the board
/LED - Haptic - Buzzer - Touch/MOTOR_EN: Q1.1 (G), R10.2, TP14.1; also elsewhere on the board
/LED - Haptic - Buzzer - Touch/TOUCH_IO2: J2.2; also elsewhere on the board
/LED - Haptic - Buzzer - Touch/TOUCH_IO3: J2.4; also elsewhere on the board
/LED - Haptic - Buzzer - Touch/TOUCH_IO4: J2.6; also elsewhere on the board
/LED - Haptic - Buzzer - Touch/TOUCH_SHIELD: J2.1, J2.3, J2.5, J2.7, J2.8; also elsewhere on the board
GND: C32.2, Q1.2 (S), Q2.2 (S), R10.1, R11.1, U6.7 (GND), U6.9 (EP); also elsewhere on the board
unnamed: BZ1.2 (+), Q2.3 (D)
unnamed: D1.1 (RK), D2.2 (GK), U6.4 (LED3)
unnamed: D1.2 (GK), D2.4 (A), U6.5 (LED2)
unnamed: D1.3 (BK), D2.1 (RK), U6.3 (LED4)
unnamed: D1.4 (A), D2.3 (BK), U6.6 (LED1)
unnamed: D3.2 (A), M1.2 (-), Q1.3 (D)
VDD: BZ1.1 (-), C32.1, D3.1 (K), M1.1 (+), U6.8 (VIN); also elsewhere on the board

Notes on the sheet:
Peripherals
Haptic Motor
Audio Buzzer
Touch / Gestures Flex Connector
Board LED
Features RGB Leds Haptic Feedback Audio Buzzer Touch & Gestures

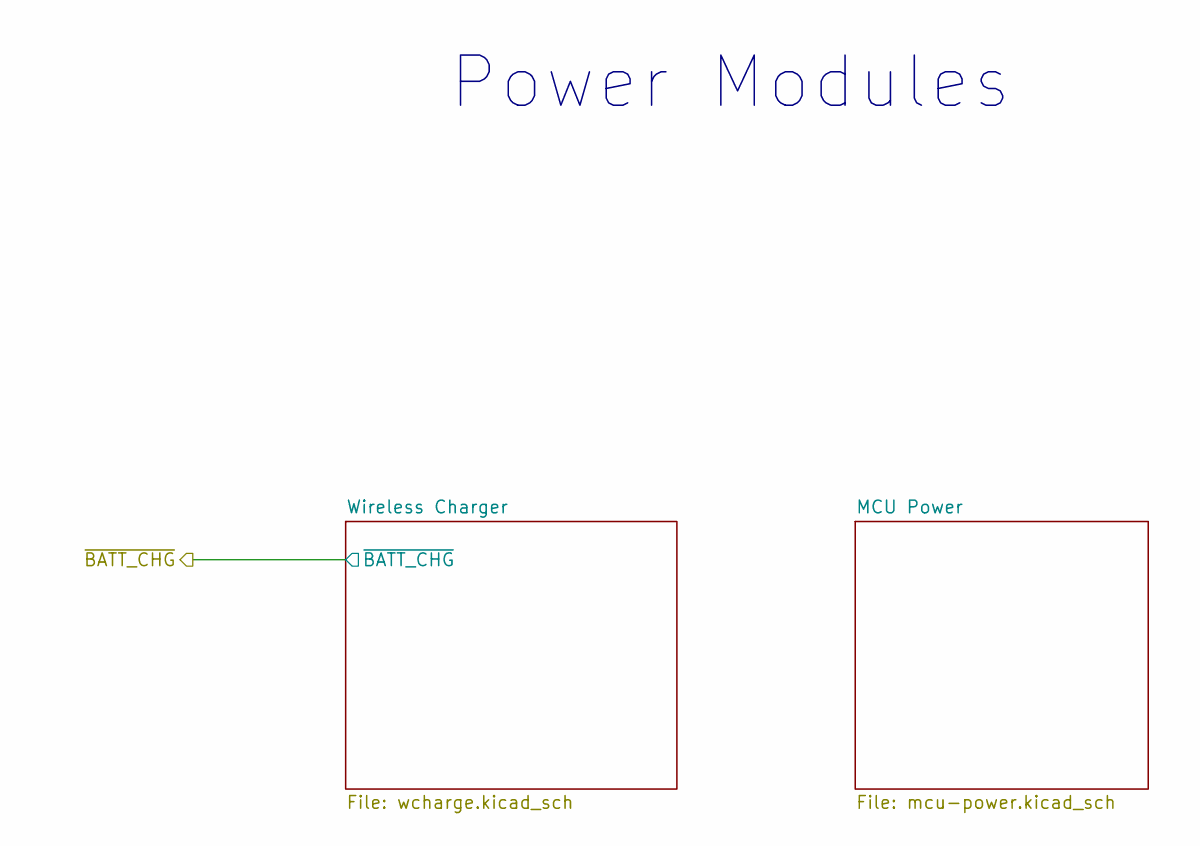
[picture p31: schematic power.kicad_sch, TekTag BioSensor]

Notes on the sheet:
Power Modules

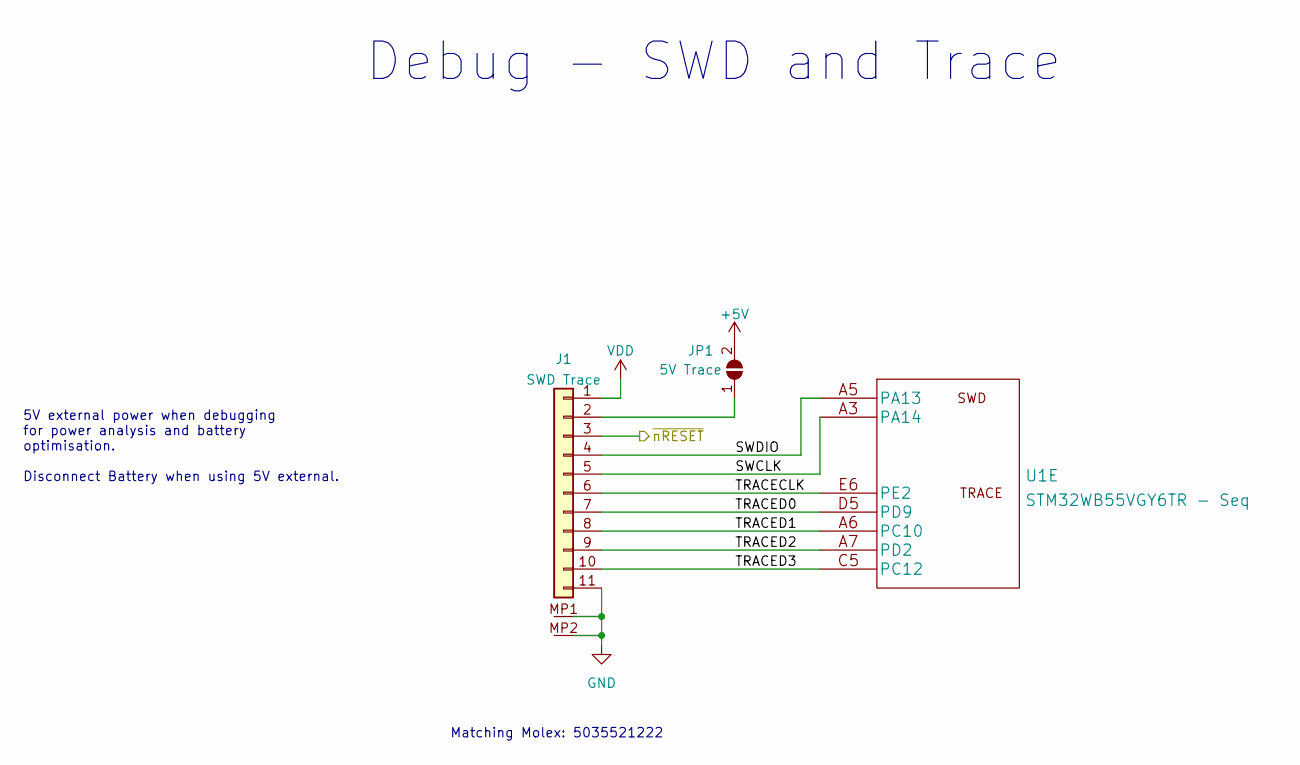
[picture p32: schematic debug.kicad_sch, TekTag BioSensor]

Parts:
J1: SWD Trace
JP1: 5V Trace
U1: STM32WB55VGY6TR - Seq

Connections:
+5V: JP1.2 (B); also elsewhere on the board
/MCU/Debug/SWCLK: J1.5, U1.A3 (PA14)
/MCU/Debug/SWDIO: J1.4, U1.A5 (PA13)
/MCU/Debug/TRACECLK: J1.6, U1.E6 (PE2)
/MCU/Debug/TRACED0: J1.7, U1.D5 (PD9)
/MCU/Debug/TRACED1: J1.8, U1.A6 (PC10)
/MCU/Debug/TRACED2: J1.9, U1.A7 (PD2)
/MCU/Debug/TRACED3: J1.10, U1.C5 (PC12)
/MCU/~nRESET: J1.3; also elsewhere on the board
GND: J1.11, J1.MP1, J1.MP2; also elsewhere on the board
unnamed: J1.2, JP1.1 (A)
VDD: J1.1; also elsewhere on the board

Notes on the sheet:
5V external power when debugging for power analysis and battery optimisation. Disconnect Battery when using 5V external.
Debug - SWD and Trace
Matching Molex: 5035521222

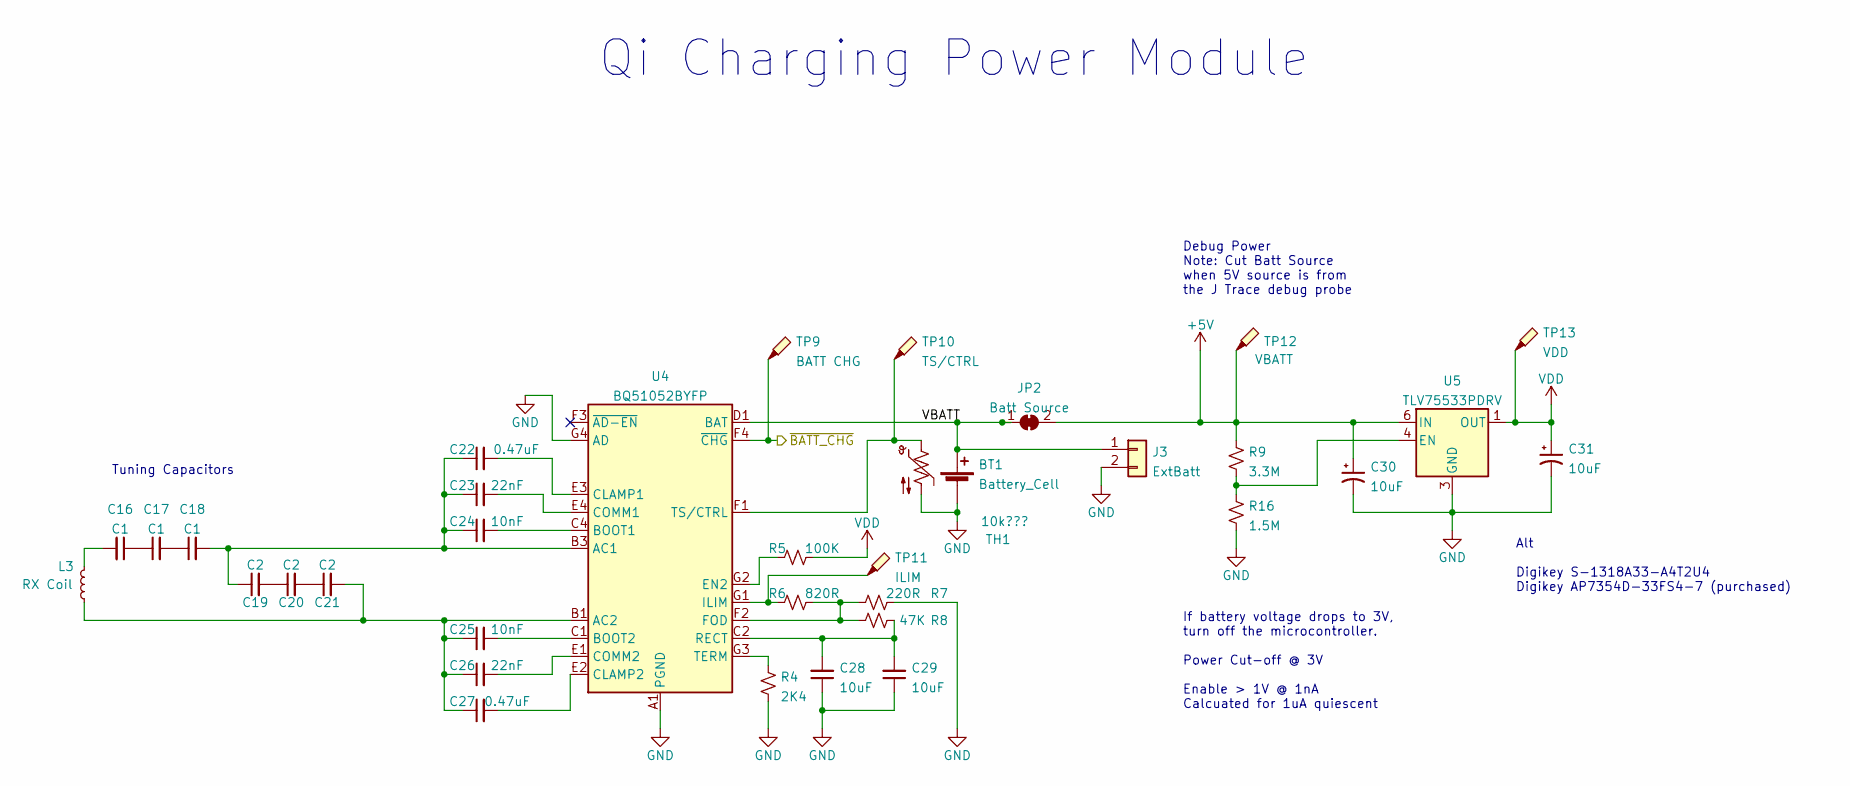
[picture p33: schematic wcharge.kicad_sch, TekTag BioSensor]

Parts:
BT1: Battery_Cell
C16, C17, C18: C1
C19, C20, C21: C2
C22, C27: 0.47uF; Digikey GRM155R71H473KE14J
C23, C26: 22nF; Digikey GRM155R71H223KA12D
C24, C25: 10nF; Digikey GCM155R71H103KA55J
C28, C29: 10uF
C30, C31: 10uF; Digikey GRM188R6YA106MA73D
J3: ExtBatt
JP2: Batt Source
L3: RX Coil
R4: 2K4; Digikey 311-2.40KLRCT-ND
R5: 100K; Digikey 311-100KLRCT-ND
R6: 820R; Digikey 311-820LRCT-ND
R7: 220R; Digikey 311-220LRCT-ND
R8: 47K; Digikey 311-47.0KLRCT-ND
R9: 3.3M; Digikey 311-3.30MLRCT-ND
R16: 1.5M; Digikey YAG5650CT-ND
TH1: 10k???
TP9: BATT CHG
TP10: TS/CTRL
TP11: ILIM
TP12: VBATT
TP13: VDD
U4: BQ51052BYFP
U5: TLV75533PDRV; Digikey 296-51807-2-ND

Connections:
+5V: C30.1, JP2.2 (B), R9.2, TP12.1, U5.6 (IN); also elsewhere on the board
/MCU/~BATT_CHG: TP9.1, U4.F4 (~CHG); also elsewhere on the board
/Power & Qi Charging/Wireless Charger/VBATT: BT1.1 (+), J3.1, JP2.1 (A), U4.D1 (BAT), U4.D2 (BAT), U4.D3 (BAT), U4.D4 (BAT)
GND: BT1.2 (-), C28.1, C29.1, C30.2, C31.2, J3.2, R4.1, R7.2, R16.1, TH1.2, U4.A1 (PGND), U4.A2 (PGND), U4.A3 (PGND), U4.A4 (PGND), U4.G4 (AD), U5.3 (GND), U5.7 (GND); also elsewhere on the board
unnamed: C16.1, C17.1
unnamed: C16.2, L3.2
unnamed: C17.2, C18.1
unnamed: C18.2, C19.1, C22.1, C23.1, C24.1, U4.B3 (AC1), U4.B4 (AC1)
unnamed: C19.2, C20.1
unnamed: C20.2, C21.1
unnamed: C21.2, C25.1, C26.1, C27.1, L3.1, U4.B1 (AC2), U4.B2 (AC2)
unnamed: C22.2, U4.E3 (CLAMP1)
unnamed: C23.2, U4.E4 (COMM1)
unnamed: C24.2, U4.C4 (BOOT1)
unnamed: C25.2, U4.C1 (BOOT2)
unnamed: C26.2, U4.E1 (COMM2)
unnamed: C27.2, U4.E2 (CLAMP2)
unnamed: C28.2, C29.2, R8.2, U4.C2 (RECT), U4.C3 (RECT)
unnamed: R4.2, U4.G3 (TERM)
unnamed: R5.1, U4.G2 (EN2)
unnamed: R6.1, TP11.1, U4.G1 (ILIM)
unnamed: R6.2, R7.1, R8.1, U4.F2 (FOD)
unnamed: R9.1, R16.2, U5.4 (EN)
unnamed: TH1.1, TP10.1, U4.F1 (TS/CTRL)
VDD: C31.1, R5.2, TP13.1, U5.1 (OUT); also elsewhere on the board

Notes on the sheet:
Debug Power Note: Cut Batt Source when 5V source is from the J Trace debug probe
Tuning Capacitors
Alt Digikey S-1318A33-A4T2U4 Digikey AP7354D-33FS4-7 (purchased)
If battery voltage drops to 3V, turn off the microcontroller. Power Cut-off @ 3V Enable > 1V @ 1nA Calcuated for 1uA quiescent
Qi Charging Power Module

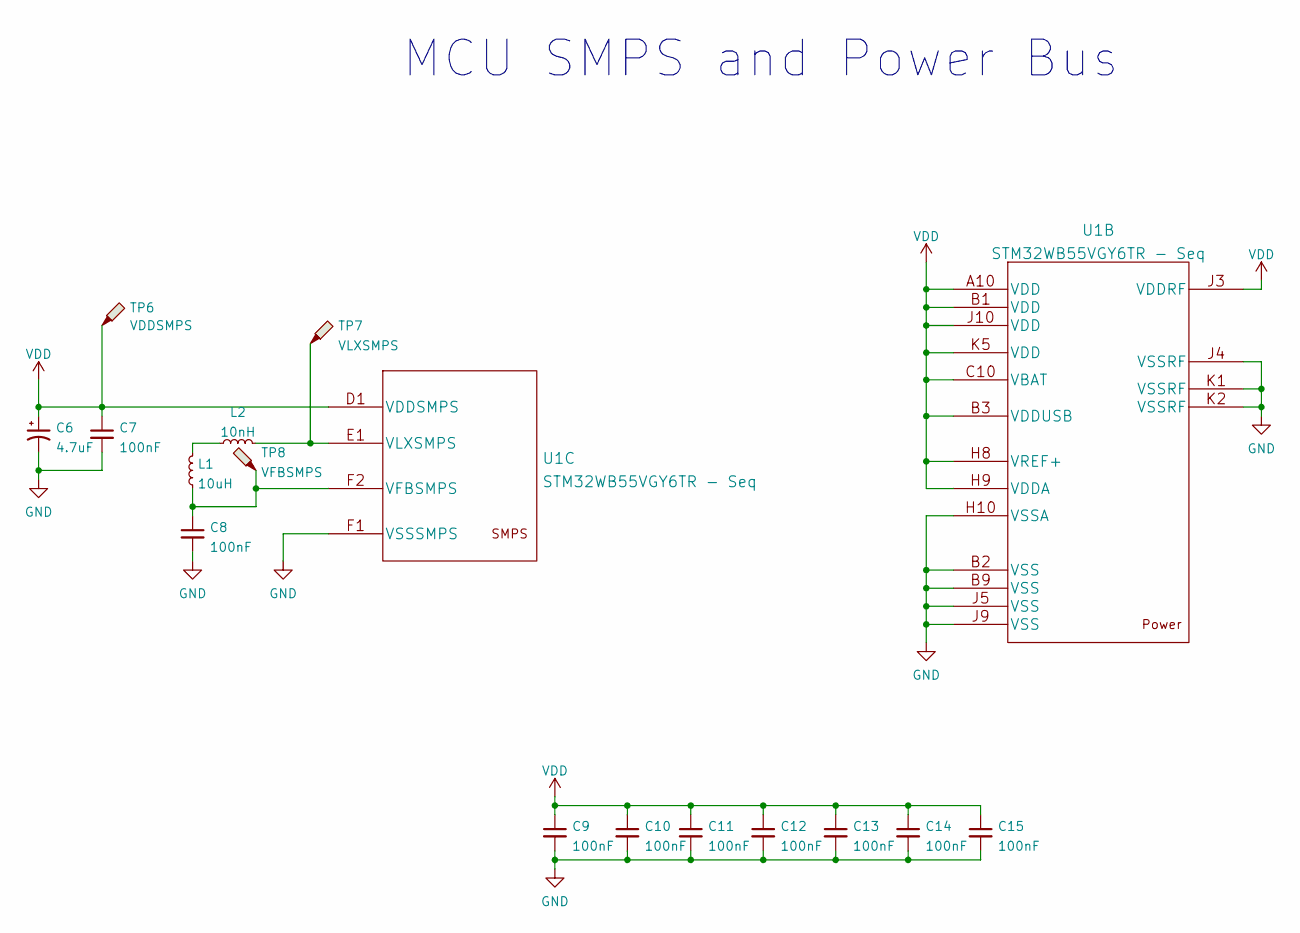
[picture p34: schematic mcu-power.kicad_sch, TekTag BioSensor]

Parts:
C6: 4.7uF; Digikey F981C475MMA
C7, C8, C9, C10, C11, C12, C13, C14, C15: 100nF; Digikey GRT155R71H104KE01D
L1: 10uH; Digikey MLZ1608N100LTD25
L2: 10nH; Digikey 7447860110G
TP6: VDDSMPS
TP7: VLXSMPS
TP8: VFBSMPS
U1: STM32WB55VGY6TR - Seq

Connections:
GND: C6.2, C7.2, C8.2, C9.2, C10.2, C11.2, C12.2, C13.2, C14.2, C15.2, U1.B2 (VSS), U1.B9 (VSS), U1.F1 (VSSSMPS), U1.H10 (VSSA), U1.J4 (VSSRF), U1.J5 (VSS), U1.J9 (VSS), U1.K1 (VSSRF), U1.K2 (VSSRF); also elsewhere on the board
unnamed: C8.1, L1.1, TP8.1, U1.F2 (VFBSMPS)
unnamed: L1.2, L2.1
unnamed: L2.2, TP7.1, U1.E1 (VLXSMPS)
VDD: C6.1, C7.1, C9.1, C10.1, C11.1, C12.1, C13.1, C14.1, C15.1, TP6.1, U1.A10 (VDD), U1.B1 (VDD), U1.B3 (VDDUSB), U1.C10 (VBAT), U1.D1 (VDDSMPS), U1.H8 (VREF+), U1.H9 (VDDA), U1.J3 (VDDRF), U1.J10 (VDD), U1.K5 (VDD); also elsewhere on the board

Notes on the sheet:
MCU SMPS and Power Bus

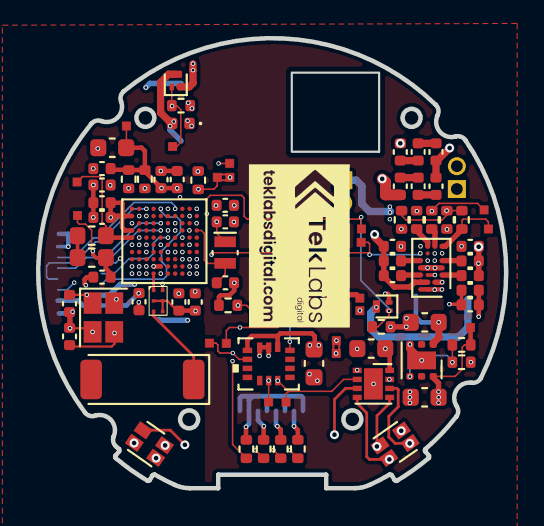
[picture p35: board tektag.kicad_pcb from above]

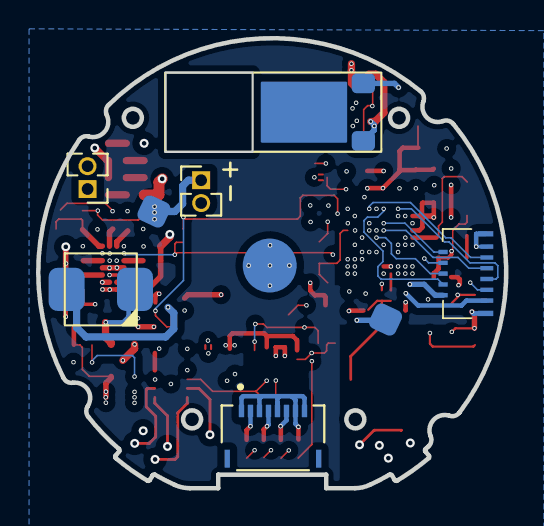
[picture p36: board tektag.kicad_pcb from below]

Board: 6 copper layers, 26.0 x 25.0 mm, 92 parts (7 on the bottom side), 66 nets.

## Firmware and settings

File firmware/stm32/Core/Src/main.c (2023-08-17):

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
/* Includes ------------------------------------------------------------------*/
#include "main.h"
#include "i2c.h"
#include "ipcc.h"
#include "rf.h"
#include "rtc.h"
#include "tsc.h"
#include "gpio.h"

/* USER CODE BEGIN Includes */

#include "app.h"

/* USER CODE END Includes */


void SystemClock_Config(void);
void PeriphCommonClock_Config(void);
/* USER CODE BEGIN 0 */
void start_trace(void) {
    // 1. Initialization
    GPIO_InitTypeDef GPIO_InitStruct = {0};
//    uint32_t prescaler_value = 1;

    // 2. Initialize variables
    __HAL_RCC_GPIOC_CLK_ENABLE();
    __HAL_RCC_GPIOD_CLK_ENABLE();
    __HAL_RCC_GPIOE_CLK_ENABLE();

    // 3. Set the default trace port width
//    TPI->CSPSR = 4;

    // 4. Initialize the speed for the Trace Clock and Trace Data signals
    GPIO_InitStruct.Mode = GPIO_MODE_AF_PP;
    GPIO_InitStruct.Pull = GPIO_NOPULL;
    GPIO_InitStruct.Speed = GPIO_SPEED_FREQ_VERY_HIGH;

    // 5. Begin the process of configuring the GPIO pins for trace functionality
    // TRACECLK
    GPIO_InitStruct.Pin = GPIO_PIN_2;
    GPIO_InitStruct.Alternate = GPIO_AF0_TRACECK;
    HAL_GPIO_Init(GPIOE, &GPIO_InitStruct);

    // 6. Repeat these configuration steps for each trace data pin
    // TRACED0
    GPIO_InitStruct.Pin = GPIO_PIN_9;
    GPIO_InitStruct.Alternate = GPIO_AF0_TRACED0;
    HAL_GPIO_Init(GPIOD, &GPIO_InitStruct);

    // TRACED1
    GPIO_InitStruct.Pin = GPIO_PIN_10;
    GPIO_InitStruct.Alternate = GPIO_AF0_TRACED1;
    HAL_GPIO_Init(GPIOC, &GPIO_InitStruct);

    // TRACED2
    GPIO_InitStruct.Pin = GPIO_PIN_2;
    GPIO_InitStruct.Alternate = GPIO_AF0_TRACED2;
    HAL_GPIO_Init(GPIOD, &GPIO_InitStruct);

    // TRACED3
    GPIO_InitStruct.Pin = GPIO_PIN_12;
    GPIO_InitStruct.Alternate = GPIO_AF0_TRACED3;
    HAL_GPIO_Init(GPIOC, &GPIO_InitStruct);

//    // 7. Enable trace functionality
//    // Set the PRESCALER in the Asynchronous Clock Prescaler Register (ACPR)
//    TPI->ACPR = (TPI->ACPR & ~TPI_ACPR_PRESCALER_Msk) | ((prescaler_value << TPI_ACPR_PRESCALER_Pos) & TPI_ACPR_PRESCALER_Msk);
//
//    // Set the TXMODE in the Selected Pin Protocol Register (SPPR) to use NRZ (Non-return to zero)
//    TPI->SPPR = (TPI->SPPR & ~TPI_SPPR_TXMODE_Msk) | ((0x0 << TPI_SPPR_TXMODE_Pos) & TPI_SPPR_TXMODE_Msk);
//
//    // Enable continuous formatting and comparison in the Formatter and Flush Control Register (FFCR)
//    TPI->FFCR |= TPI_FFCR_EnFCont_Msk;

    // 8. Conclude the function
    // Additional trace-specific register settings for ITM, DWT, and ETM might go here, if needed.
    LL_DBGMCU_EnableTraceClock();
}


/* USER CODE END 0 */

/**
  * @brief  The application entry point.
  * @retval int
  */
int main(void)
{
  /* USER CODE BEGIN 1 */
	  start_trace();
  /* USER CODE END 1 */

  /* MCU Configuration--------------------------------------------------------*/

  /* Reset of all peripherals, Initializes the Flash interface and the Systick. */
  HAL_Init();
  /* Config code for STM32_WPAN (HSE Tuning must be done before system clock configuration) */
  MX_APPE_Config();

  /* Configure the system clock */
  SystemClock_Config();

/* Configure the peripherals common clocks */
  PeriphCommonClock_Config();

  /* IPCC initialisation */
  MX_IPCC_Init();

  /* Initialize all configured peripherals */
  MX_GPIO_Init();
  MX_I2C1_Init();
  MX_TSC_Init();
  MX_RTC_Init();
  MX_RF_Init();
  /* Init code for STM32_WPAN */
  MX_APPE_Init();

  /* Infinite loop */
  /* USER CODE BEGIN WHILE */

  setup();

  while (1)
  {
	loop();
    /* USER CODE END WHILE */
    MX_APPE_Process();

    /* USER CODE BEGIN 3 */
  }
  /* USER CODE END 3 */
}

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


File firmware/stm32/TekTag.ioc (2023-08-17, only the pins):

Mcu.UserName=STM32WB55VGYx
PA0.GPIO_Label=MOTOR_EN
PA0.Signal=GPIO_Output
PA1.Signal=GPIO_Output
PA13.Signal=SYS_JTMS-SWDIO
PA14.Signal=SYS_JTCK-SWCLK
PA4.GPIO_Label=IMU_INT1
PA4.Signal=GPXTI4
PA5.GPIO_Label=IMU_INT2
PA5.Signal=GPXTI5
PB12.GPIO_Label=TOUCH_SCAP
PB12.Signal=TSC_G1_IO1
PB13.GPIO_Label=TOUCH_IO2
PB13.Signal=TSC_G1_IO2
PB14.GPIO_Label=TOUCH_IO3
PB14.Signal=TSC_G1_IO3
PB15.GPIO_Label=TOUCH_IO4G
PB15.Signal=TSC_G1_IO4
PB4.GPIO_Label=TOUCH_G2_SCAP
PB4.Signal=TSC_G2_IO1
PB5.GPIO_Label=TOUCH_G2_SHIELD
PB5.Signal=TSC_G2_IO2
PB6.Signal=I2C1_SCL
PB7.Signal=I2C1_SDA
PC1.GPIO_Label=BATT_CHG
PC1.Signal=GPXTI1
PC10.Signal=SYS_TRACED1
PC12.Signal=SYS_TRACED3
PC14-OSC32_IN.Signal=RCC_OSC32_IN
PC15-OSC32_OUT.Signal=RCC_OSC32_OUT
PD2.Signal=SYS_TRACED2
PD9.Signal=SYS_TRACED0
PE2.Signal=SYS_TRACECLK

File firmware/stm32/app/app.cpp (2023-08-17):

#include "app.h"

#include <drivers/kt2052.h>

extern "C" {

I2CPeripheral i2c1(hi2c1, KTD2052_ADDRESS);
kt2052 myDevice(i2c1);

void setup() {
	myDevice.Setup();

    KTD2052_ID_t id = myDevice.GetID();
    printf("Vendor ID: %d, Die ID: %d\n", id.vendor, id.die_id);

    // Configure the Pattern Generator Mode
    myDevice.Configure(1, 1, 00, 0);

    myDevice.SetLED1Intensity(0, 45, 45);
    myDevice.SetLED2Intensity(45, 45, 0);

}

uint8_t red = 0;
uint8_t green = 0;
uint8_t blue = 0;

void loop() {
    red += 1;
    green += 1;
    blue += 1;
////
////    // Apply the updated RGB values to LEDs
    myDevice.SetLED1Intensity(red, green, blue);
    myDevice.SetLED2Intensity(red, green, blue);
    HAL_Delay(100);


}

} // extern "C"

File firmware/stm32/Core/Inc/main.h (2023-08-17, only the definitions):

#define TOUCH_IO2_Pin GPIO_PIN_13
#define TOUCH_IO2_GPIO_Port GPIOB
#define TOUCH_G2_SCAP_Pin GPIO_PIN_4
#define TOUCH_G2_SCAP_GPIO_Port GPIOB
#define TOUCH_G2_SHIELD_Pin GPIO_PIN_5
#define TOUCH_G2_SHIELD_GPIO_Port GPIOB
#define TOUCH_IO3_Pin GPIO_PIN_14
#define TOUCH_IO3_GPIO_Port GPIOB
#define TOUCH_IO4G_Pin GPIO_PIN_15
#define TOUCH_IO4G_GPIO_Port GPIOB
#define TOUCH_SCAP_Pin GPIO_PIN_12
#define TOUCH_SCAP_GPIO_Port GPIOB
#define MOTOR_EN_Pin GPIO_PIN_0
#define MOTOR_EN_GPIO_Port GPIOA
#define BATT_CHG_Pin GPIO_PIN_1
#define BATT_CHG_GPIO_Port GPIOC
#define IMU_INT2_Pin GPIO_PIN_5
#define IMU_INT2_GPIO_Port GPIOA
#define IMU_INT1_Pin GPIO_PIN_4
#define IMU_INT1_GPIO_Port GPIOA

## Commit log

2023-06-12 Added Mechanical Files
    [ASSEMBLY FULL.SLDASM, ASSEMBLY PCB.SLDASM, ASSEMBLY WIRELESS CHARGING.SLDASM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]
2023-06-12 PCB Image Update
2023-06-28 BOM update
    [bom.csv, debug.kicad_sch, debug_board.kicad_pcb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]
2023-08-17 Hardware and Firmware udpates
    [bom.csv, debug_board.kicad_pcb, debug_board.kicad_sch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]

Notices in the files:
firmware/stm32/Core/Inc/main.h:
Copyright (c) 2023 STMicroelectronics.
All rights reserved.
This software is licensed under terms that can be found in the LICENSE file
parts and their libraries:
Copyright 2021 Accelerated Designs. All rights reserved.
